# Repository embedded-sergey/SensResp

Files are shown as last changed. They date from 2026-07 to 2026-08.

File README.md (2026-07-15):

# SensResp
SensResp is a dissolved‑oxygen transmitter for galvanic probes used in intermittent‑flow aquatic respirometry.   It works together with [PumpResp](https://github.com/yourusername/PumpResp) by acquiring pump phase from it, then transmitting data over USB to a PC for logging.

It is part of the FishResp project (more information at https://fishresp.org).

## Build Guide
The complete assembly, wiring, calibration, and safety instructions are provided in: `docs/SensResp_Build_Guide.md`

This README intentionally avoids duplicating the Build Guide.

## Licensing
SensResp uses a multi‑license structure:

- **Hardware designs:** CERN‑OHL‑S v2  
- **Software:** GPL‑3.0  
- **Documentation:** CC‑BY‑4.0  

Mixed‑content files (e.g., documentation containing schematics or code snippets) are governed by the license of each component.

See the **LICENSE** file for the human‑readable overview and the `LICENSES/` directory for full legal texts.

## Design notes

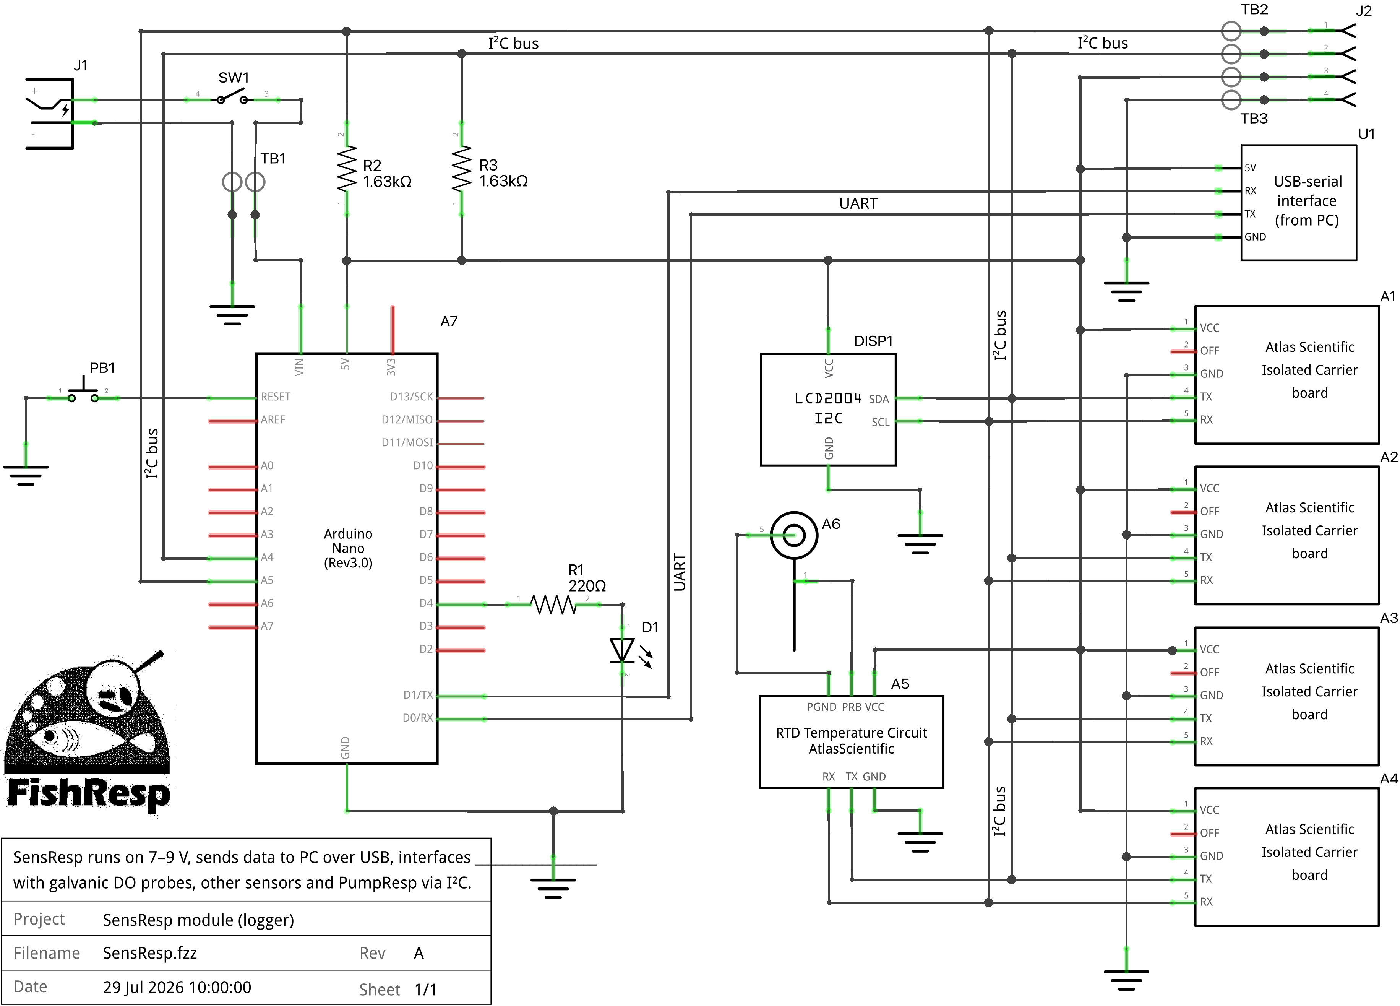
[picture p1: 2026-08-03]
docs/images/SensResp_schematics.png

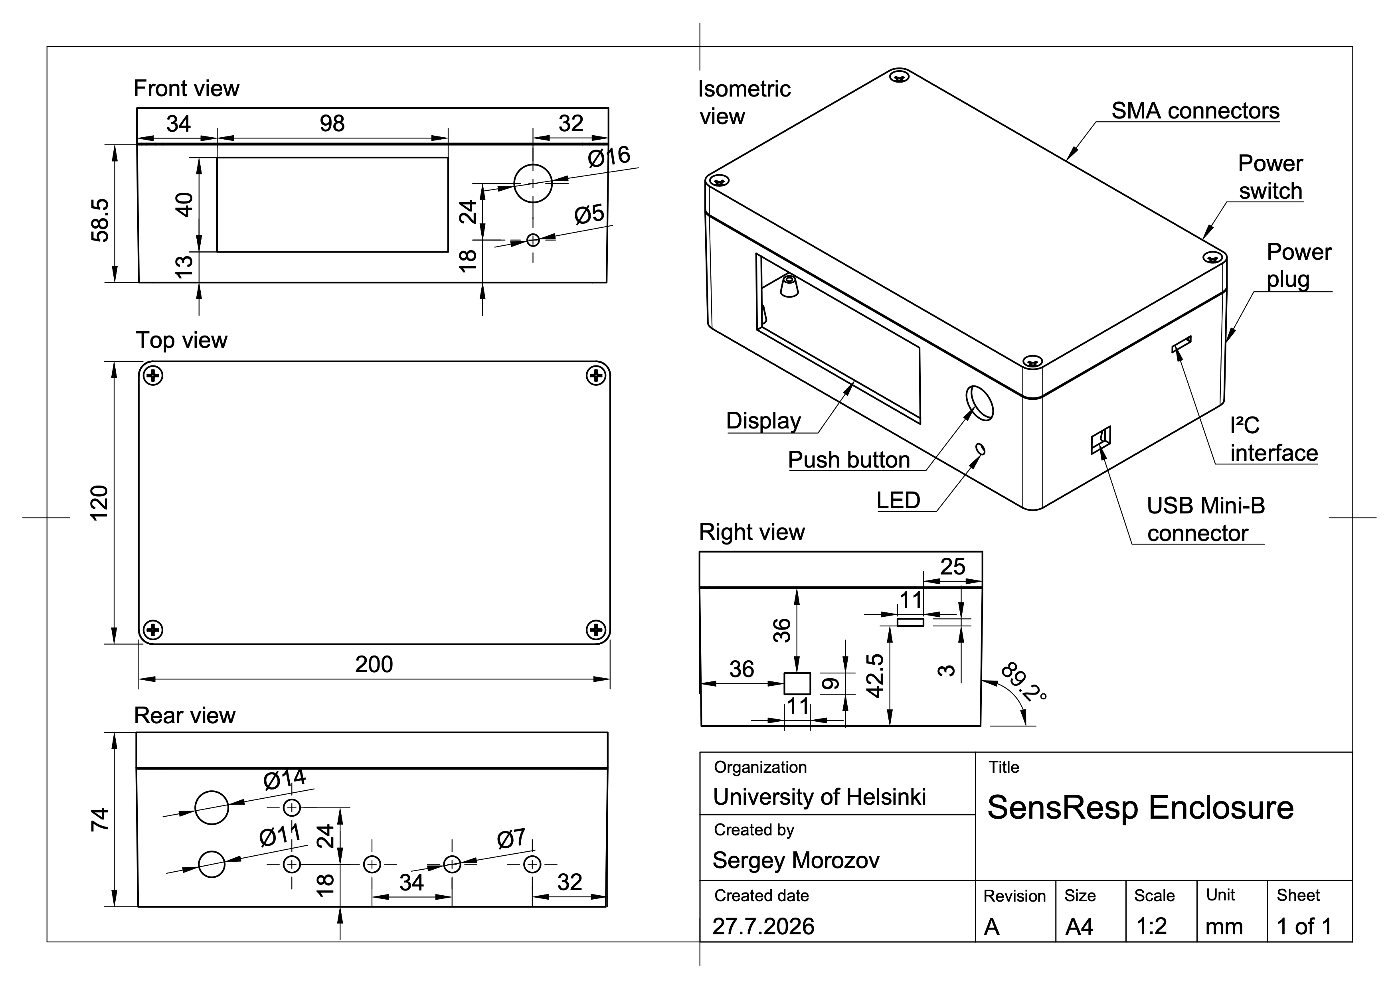
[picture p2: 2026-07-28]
docs/images/SensResp_enclosure_blueprint.png

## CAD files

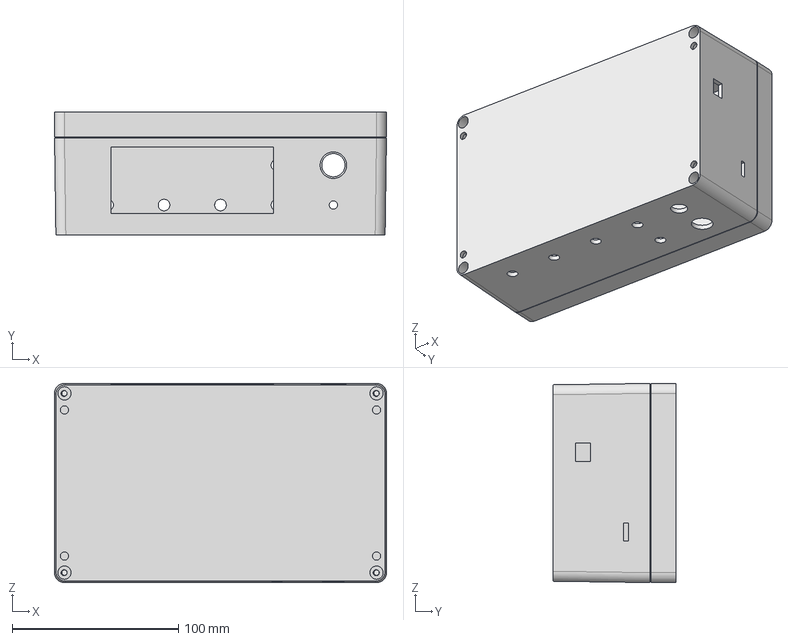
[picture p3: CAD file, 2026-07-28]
hardware/cad/SensResp_enclosure_assembly.step
200.0 x 74.0 x 120.0 mm

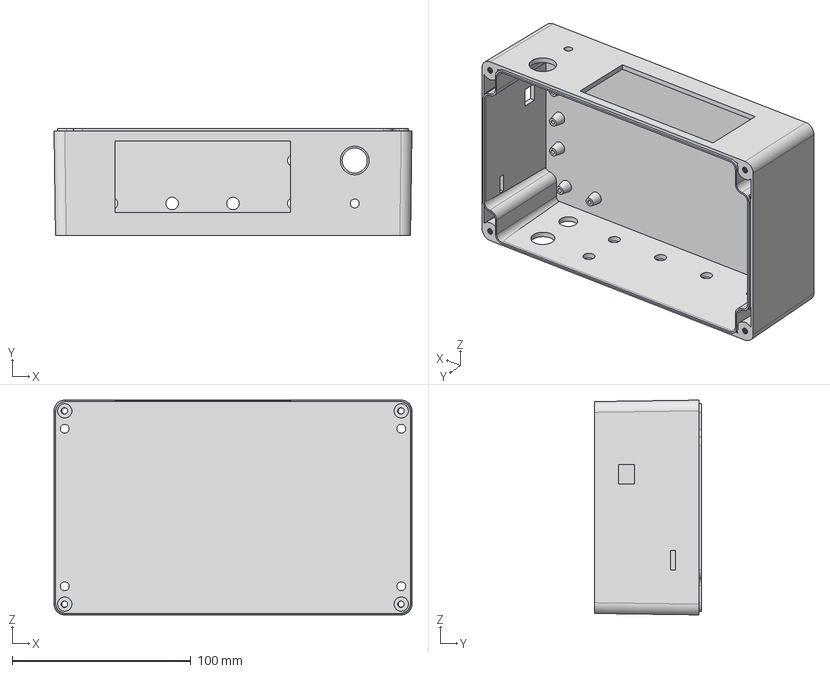
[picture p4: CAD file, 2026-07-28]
hardware/cad/SensResp_enclosure_base.step
200.0 x 60.0 x 120.0 mm

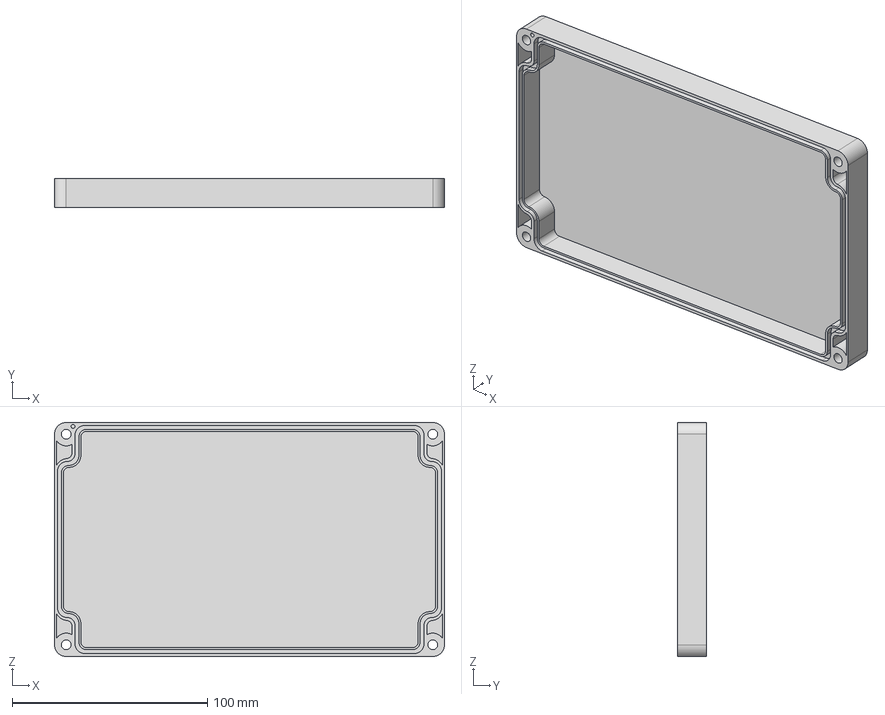
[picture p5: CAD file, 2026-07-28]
hardware/cad/SensResp_enclosure_cover.step
200.0 x 15.0 x 120.0 mm

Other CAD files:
hardware/stl/SensResp_enclosure_base.stl
hardware/stl/SensResp_enclosure_cover.stl

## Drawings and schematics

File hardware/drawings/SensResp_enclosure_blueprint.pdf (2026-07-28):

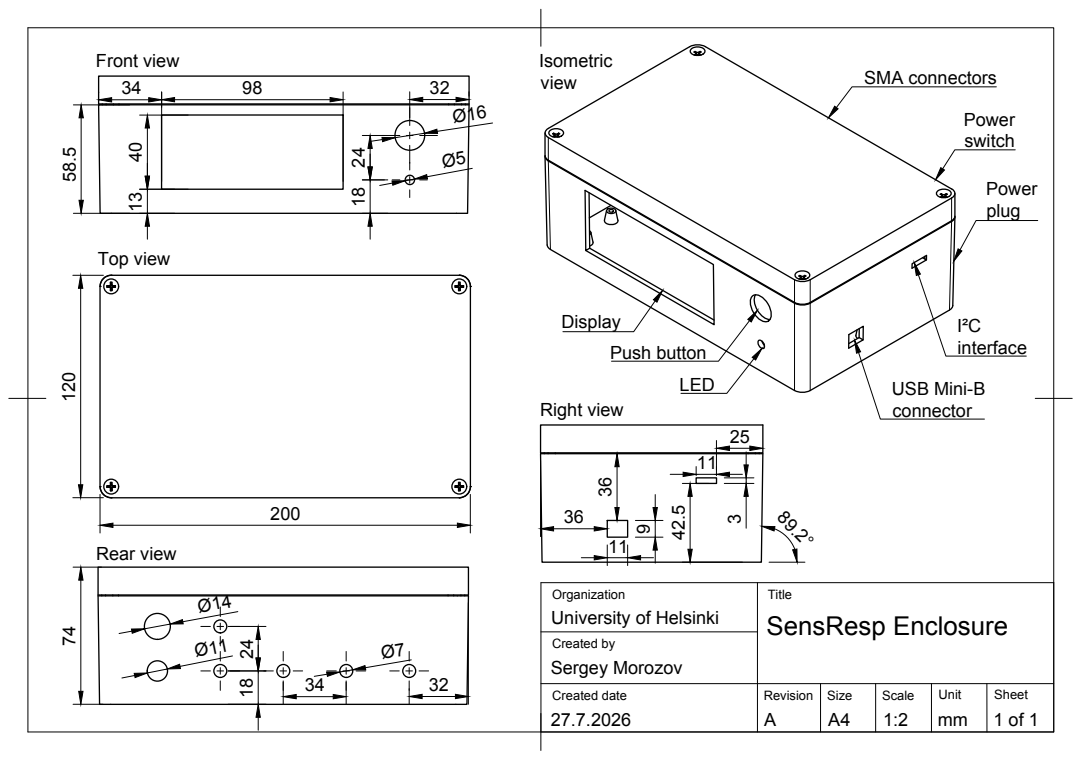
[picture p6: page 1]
SMA connectors; USB Mini-B; Front view; Top view; Rear view; Right view; Created by; Created date; Revision; Size; Scale; SensResp Enclosure; Sergey Morozov; Push button

University of Helsinki

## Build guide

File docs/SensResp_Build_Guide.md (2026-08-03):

---
title: "SensResp Build Guide"
author: "Sergey Morozov"
date: "2 August 2026"
revision: "0.3"
toc: true
toc-depth: 3
---

# SensResp Build Guide
**Revision:** 0.3 
**Author:** Sergey Morozov  
**Date:** 2 August 2026

<!-- begin-md-image -->
SensResp Device
<!-- end-md-image -->

# Table of Contents

1. [Introduction](#1-introduction)
2. [Safety Notes](#2-safety-notes)  
   2.1 [Environmental Safety](#21-environmental-safety)  
   2.2 [Electrical Safety](#22-electrical-safety)  
   2.3 [Mechanical and Tool Safety](#23-mechanical-and-tool-safety)
3. [Bill of Materials](#3-bill-of-materials)
4. [Tools and Consumables](#4-tools-and-consumables)

---

# 1. Introduction

SensResp is an open‑source device for acquiring dissolved‑oxygen and temperature data from multiple Atlas Scientific probes. All measurements are visualized on an LCD display and transmitted to a computer over USB for logging and real‑time plotting. The entire system is assembled on a solderless breadboard, allowing additional sensors or components to be added with minimal modification. SensResp integrates with the PumpResp controller by fetching pump‑phase information and enabling threshold‑based pump activation in addition to time‑based control.

This guide explains how to assemble the hardware step by step. It covers preparing the enclosure, wiring the electronics, installing the user‑interface components, and loading the software. The document focuses strictly on construction and verification; experimental applications and biological context are described separately in the accompanying manuscript.

**User skill level.** The build guide is intended for students, technicians, and researchers with basic technical skills. No engineering background is required. Users should be comfortable with simple soldering and basic multimeter measurements (continuity and DC voltage).

**Assembly environment.** SensResp can be assembled in any standard workspace equipped for basic electronics and mechanical tasks, including university or biological‑station workshops, applied‑sciences laboratories, or local FabLabs (a global directory is provided by the Fab Foundation). The enclosure can be purchased and modified or fabricated using a 3D printer.

**Estimated build time.** Assembly, software setup, and full functional verification typically require 1–2 days for a first‑time build depending on user skills. When assembling multiple identical units, the per‑device time decreases substantially as enclosure preparation and wiring become more routine.

## Versioning

This guide corresponds to SensResp hardware, software, and documentation release **v1.0.0**.

Source files and updates are available in the public repository:  
<https://github.com/embedded-sergey/SensResp>

## Licensing

- **Software:** GPL‑3.0  
- **Hardware designs:** CERN-OHL-S v2 
- **Documentation (including this guide):** CC‑BY‑4.0  

These licenses ensure open access, modifiability, and reproducibility across all components of the SensResp platform. If this guide contains hardware diagrams or code snippets, those components are licensed under their respective hardware or software licenses.

# 2. Safety Notes

## 2.1 Environmental Safety

SensResp is designed to be water-resistant, providing protection against accidental splashes and operation in high humidity environments. To reduce moisture accumulation in humid environment, place an absorbent pack inside the enclosure. SensResp is not waterproof: if the device is submerged or dropped into the water, immediately power it off, disconnect the USB cable and do not resume operation until the enclosure and internal components have been thoroughly inspected and dried.

## 2.2 Electrical Safety

SensResp operates at 5-9 VDC, which falls within the extra-low-voltage category recognized in electrical safety standards worldwide. Devices operating at ≤ 24 VDC are generally considered safe for personal, educational, and research use, and in most countries can be built and used without electrical certification, provided that a certified external power supply is used and no mains‑voltage wiring is modified. 

The power supply unit must include integrated overcurrent protection (fuse or electronic current limit) and should be selected according to the total power requirements of the connected devices. SensResp draws less than 300 mA at a 5 V operating voltage, so a 7–9 V, 0.5 A power supply provides sufficient overhead, operating at roughly 70% of its maximum rated output. 

During assembly and testing, follow basic electrical‑safety practices. Keep the device disconnected from any power source while you work. Check the polarity of every wire before connecting power, and avoid any contact between the positive and negative lines. Before turning the device on, inspect all solder joints, connectors, and insulation to make sure nothing is loose or exposed. Use a multimeter to check your wiring: confirm that each connection has continuity and make sure there are no accidental shorts. Switch the device on only when you’re sure all connections are correct.

## 2.3 Mechanical and Tool Safety

Use adhesive materials, mechanical and electrical tools listed in the section "Tools and Consumables” with care. If you are inexperienced with some of them, seek assistance from a trained technician. Wear personal protection equipment: protective glasses and fume mask, especially when soldering and use heat‑resistant mat to protect your workspace. During the assembly process run the tests referred in the assembly instructions to make the assembly process to be safe and verify the quality of SensResp.

# 3. Bill of Materials

Price estimates for generic components use Amazon.com  as a reference, based on pricing available in August 2026. Amazon is chosen because it provides broad international availability, relatively stable pricing, and consistent product listings, which makes it a practical baseline for reproducible cost estimates. Because many components on Amazon are sold only in bulk packs, the bill of materials lists the price of the entire pack even when only one piece is needed, which inflates the apparent cost of a single device and results in unnecessary surplus. In practice, individual components can often be purchased at lower cost from suppliers that support small‑quantity or single‑unit purchasing, including local electronics stores, online marketplaces, and global engineering distributors such as Mouser or Digi‑Key. Prices for specialized sensors and measurement devices are taken directly from manufacturers’ websites when these items are not consistently available through the above distributors.

Prices listed in this BOM exclude VAT, customs duties, and delivery costs.

| Part Name | Manufacturer | Quantity | Unit Price (USD)¹ | Total Price (USD) | Notes |
|---|---|---|---|---|---|
| Industrial ABS enclosure, IP65, 200×120×75 mm | Generic | 1 pc | 10 | 10 | – |
| Round rocker switch, mounting hole diameter 15 mm, 2-pin | Generic | 1 pc | 6 | 6 | Bulk pack (3–5 pcs) |
| DC power jack, steel, 5.5×2.1 mm | Generic | 1 pc | 7 | 7 | Bulk pack (3–5 pcs) |
| Arduino Nano–compatible board (ATmega328P) with Mini-B USB cable and screw‑terminal adapter | Generic | 1 kit | 9 | 9 | The board can be replaced by the Arduino Nano rev.3 or 3.3 V-board from Nano family² |
| Push button, mounting hole diameter 16 mm, 2-pin | Generic | 1 pc | 10 | 10 | Bulk pack (10-24 pcs) |
| LED, 5 mm | Generic | 1 pc | 6 | 6 | Bulk pack (50–200 pcs) |
| Resistor, 220 Ω, ¼ W | Generic | 1 pc | 6 | 6 | Bulk pack (20–200 pcs) |
| Resistor, 1.6 kΩ, ¼ W | Generic | 2 pcs | 6 | 6 | Bulk pack (20–200 pcs) |
| Screw terminal block connector, 2-pin | Generic | 3 pcs | 4 | 4 | Bulk pack (20–50 pcs) |
| 20x4 LCD with I²C interface, HD44780 driver, 5V | Generic | 1 pc | 10 | 10 | - |
| Female to male jumper wires, square jumpers, 10 cm | Generic | 1 kit | 5 | 5 | – |
| Solderless breadboard BB830, 165.1 x 54.6 x 8.5 mm | Generic | 1 pc | 10 | 10 | Check reviews because cheap clones often have loose contacts, bad rails, and high resistance that disrupts I²C |
| EZO™ RTD Temperature Circuit, #EZO-RTD | Atlas Scientific | 1 pc | 36 | 36 | - |
| SMA Breakout Board, #SMA-B | Atlas Scientific | 1 pc | 8 | 8 | Compatible with PT1000 probes via SMA connector³ |
| EZO™ Dissolved Oxygen Circuit, #EZO-DO | Atlas Scientific | 4 pcs | 54 | 216 | - |
| Electrically Isolated EZO™ Carrier Board, #ISCCB-2 | Atlas Scientific | 4 pcs | 33 | 132 | Compatible with galvanic DO probes via SMA connector³ |

**Grand total: 481 USD**

*¹ Unit prices reflect the smallest purchasable quantity on Amazon.com. When only bulk packs are available, the listed price corresponds to the full pack even if a single piece is required.*

*² The design is compatible with 3.3 V‑logic Arduino Nano–family boards (e.g., Nano Every, Nano 33 IoT, Nano 33 BLE) provided that the 5 V relay module is replaced with a 3 V/3.3 V logic‑compatible relay module powered from 3–3.3 V. All other digital I/O (status LED, push button, PWM control signals) operate correctly at 3.3 V logic levels.*

*³ This BOM does not include DO probes, temperature probes, cables, or calibration consumables.*

# 4. Tools and Consumables
These items are not included in the BOM because they are general workshop supplies rather than project‑specific components, but they are still required for assembly. Most of the tools and consumables can be found in FabLabs, electronic/robotics clubs and Universities of Applied Sciences around the world.

Mechanical tools:
* utility cutter
* long-nose pliers
* wire cutters
* screwdriver
* drill with step drill bit
* rotary tool with 1 mm drill bit

Electrical tools and materials:
* soldering iron
* solder wire
* flux
* heat-shrink tubing

Adhesives:
* hot-glue gun
* hot-glue sticks
* superglue

Measuring and marking tools:
* multimeter
* ruler
* pencil

Safety tools:
* protective glasses
* fume mask
* heat-resistant mat

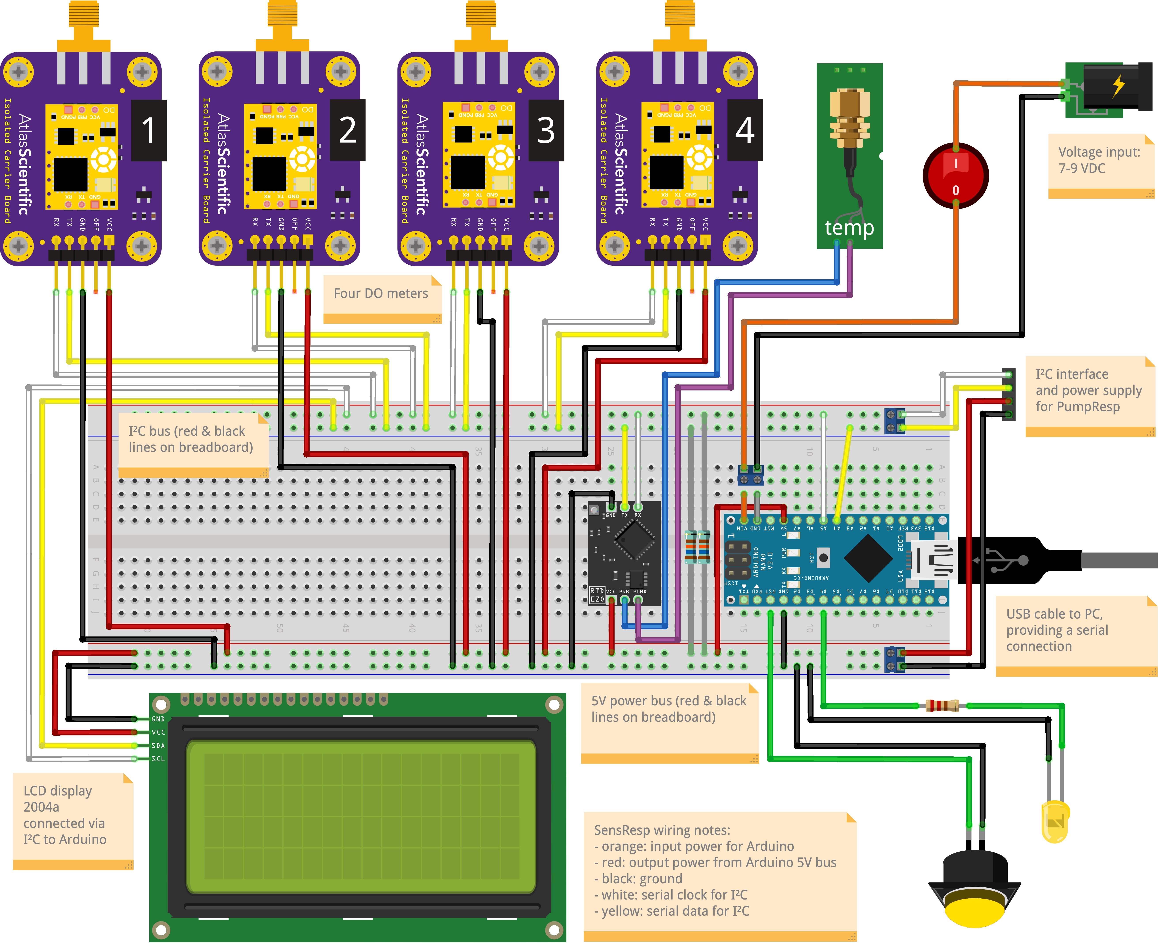
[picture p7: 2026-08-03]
docs/images/SensResp_wiring_diagram.png

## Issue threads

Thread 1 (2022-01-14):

Create a reverse function for a button

embedded-sergey, 2022-01-14:

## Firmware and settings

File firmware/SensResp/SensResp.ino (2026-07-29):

// Include following libraries to enable I2C protocol
#include <Wire.h>  // include the standard I2C library
#include <Ezo_i2c.h>  // include the EZO I2C library from https://github.com/Atlas-Scientific/Ezo_I2c_lib
#include <sequencer4.h>  // imports a 2 function sequencer
#include <Ezo_i2c_util.h>  // brings in common print statements
#include <LiquidCrystal_I2C.h>  // I2C for LCD 20x4 display

// Temperature used for DO compensation when RTD reading is invalid (safe to edit by a user)
const float static_compensation_temperature = 20.0; // if no actual or valid value from RTD received
const float invalid_temperature = -273.15; // RTD readings below this value are considered invalid

//define I2C addresses for all the sensors and devices except SensResp
#define PumpResp_address 99  // define I2C address for PumpResp
#define PumpResp_size 5  // define the maximum size of 'Phase' string from PumpResp
int LED = 4;

String phase = "";

LiquidCrystal_I2C LCD(0x27, 20, 4); // Creates I2C LCD Object With (Address=0x27, Cols=20, Rows=4)

// AtlasScientific devices are defined using their own functions:
Ezo_board RTD = Ezo_board(100, "");  // create an RTD circuit object which address is 100
Ezo_board DO_1 = Ezo_board(101, "");
Ezo_board DO_2 = Ezo_board(102, "");
Ezo_board DO_3 = Ezo_board(103, "");
Ezo_board DO_4 = Ezo_board(104, "");

// Forward declarations of functions to use them in the sequencer before defining them
void triggerPumpRespAndRTD();
void sendTemperatureToDO();
void requestDOReadings();
void collectAllData();

// Calls the steps in sequence with time in between them
Sequencer4 Seq(&triggerPumpRespAndRTD, 50,
               &sendTemperatureToDO, 300,
               &requestDOReadings, 600,
               &collectAllData, 30);

void setup(){
  Serial.begin(9600);  // start the serial communication to PC with default baud rate
  Serial.println("CLEARRANGE,A,2,H,1000000"); // trick to get rid of AM-PM
  pinMode(LED, OUTPUT);
  digitalWrite(LED, HIGH);
  
  Wire.begin();  // start the I2C without an address inside as SensResp is a master device
  
  LCD.init();
  LCD.backlight();
  LCD.noCursor();
  LCD.clear();
}


void loop() {
  Seq.run();  // run the sequencer to do the polling
}


void triggerPumpRespAndRTD() {
  // Write a start signal (i.e. zero) to the PumpResp
  Wire.beginTransmission(PumpResp_address);
  Wire.write(0);
  Wire.endTransmission();
  
  //send a read command. we use this command instead of RTD.send_cmd("R"); 
  //to let the library know to parse the reading
  RTD.send_read_cmd();
}


void sendTemperatureToDO() {
  // If the temperature reading has been received and it is valid
  if ((RTD.get_error() == Ezo_board::SUCCESS) && (RTD.get_last_received_reading() > invalid_temperature)) {  
    DO_1.send_cmd_with_num("T,", RTD.get_last_received_reading());
    DO_2.send_cmd_with_num("T,", RTD.get_last_received_reading());
    DO_3.send_cmd_with_num("T,", RTD.get_last_received_reading());
    DO_4.send_cmd_with_num("T,", RTD.get_last_received_reading());
  } else {                
    DO_1.send_cmd_with_num("T,", static_compensation_temperature);   
    DO_2.send_cmd_with_num("T,", static_compensation_temperature); 
    DO_3.send_cmd_with_num("T,", static_compensation_temperature); 
    DO_4.send_cmd_with_num("T,", static_compensation_temperature);  
  }
}


void requestDOReadings() {
  DO_1.send_read_cmd(); 
  DO_2.send_read_cmd();            
  DO_3.send_read_cmd();            
  DO_4.send_read_cmd();            
}


void collectAllData(){
  // Request data and read response from PumpResp
  Wire.requestFrom(PumpResp_address, PumpResp_size); 
  phase = ""; // add characters to a string (i.e. phase)
   while (Wire.available()) {
    char b = Wire.read();
    // Ignore common non-printable or trailing padding bytes
    if (b == '\0' || b == '\r' || b == '\n') {
      break; // Stop reading if the slave sent a terminator
    }
    phase += b;
  } 
  
  // Explicitly trim any unexpected accidental whitespace
  phase.trim();
  Serial.print(phase);
  // Get the reading from the RTD circuit
  receive_and_print_reading(RTD);
  // Get the reading from the DO circuits
  receive_and_print_reading(DO_1);
  receive_and_print_reading(DO_2);
  receive_and_print_reading(DO_3);
  receive_and_print_reading(DO_4);
  Serial.println();

  float a = RTD.get_last_received_reading();
  float b = DO_1.get_last_received_reading();
  float c = DO_2.get_last_received_reading();
  float d = DO_3.get_last_received_reading();
  float e = DO_4.get_last_received_reading();

  Serial.println((String) "DATA,DATE,TIME," + phase + (",") + a + (",") + b + (",") + c + (",")  + d + (",") + e);

  LCD_code();  // update LCD here
}


void LCD_code() {
    // Dissolved Oxygen readings
    LCD.setCursor(0, 0); LCD.print("DO1: " + String(DO_1.get_last_received_reading()) + "   ");
    LCD.setCursor(0, 1); LCD.print("DO2: " + String(DO_2.get_last_received_reading()) + "   ");
    LCD.setCursor(0, 2); LCD.print("DO3: " + String(DO_3.get_last_received_reading()) + "   ");
    LCD.setCursor(0, 3); LCD.print("DO4: " + String(DO_4.get_last_received_reading()) + "   ");

    // PumpResp phase: F - Flush, M - Measurement
    LCD.setCursor(13, 0); LCD.print("Phase:");
    LCD.setCursor(13, 1); LCD.print(phase + "  ");

    // Temperature readings
    LCD.setCursor(13, 2); LCD.print("Temp:");
    LCD.setCursor(13, 3); LCD.print(String(RTD.get_last_received_reading()) + "  ");
}


// Sources:
// 1. I2C mode instructionsfor communication between two Arduinos: 
//      https://dronebotworkshop.com/i2c-arduino-arduino/
// 2. Atlas Scientific I2C example for multiple sources:
//      https://github.com/Atlas-Scientific/Ezo_I2c_lib/blob/master/Examples/I2c_lib_examples/I2c_read_mulitple_circuits/I2c_read_mulitple_circuits.ino

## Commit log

2026-07-12 Remove PumpResp counterpart from this repo
    [PumpResp.xlsm]
2026-07-14 Create host Excel app/template
    [SensResp_template.xlsm]
2026-07-15 Add CAD files & Build Guide template
    [SensResp_enclosure_assembly.step, SensResp_enclosure_base.step, SensResp_enclosure_base.stl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]
2026-07-15 Create wiring diagram for SensResp
2026-07-28 Create blueprints & update CAD files
    [SensResp_enclosure_assembly.step, SensResp_enclosure_base.step, SensResp_enclosure_base.stl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]
2026-07-30 Create schematics and updated wiring diagram
2026-08-02 Add BOM section to SensResp Build Guide
2026-08-03 Add screw terminal blocks to schematics and wiring diagram
